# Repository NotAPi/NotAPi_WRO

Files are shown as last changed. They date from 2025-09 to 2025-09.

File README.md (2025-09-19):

# NotAPi_WRO_2025

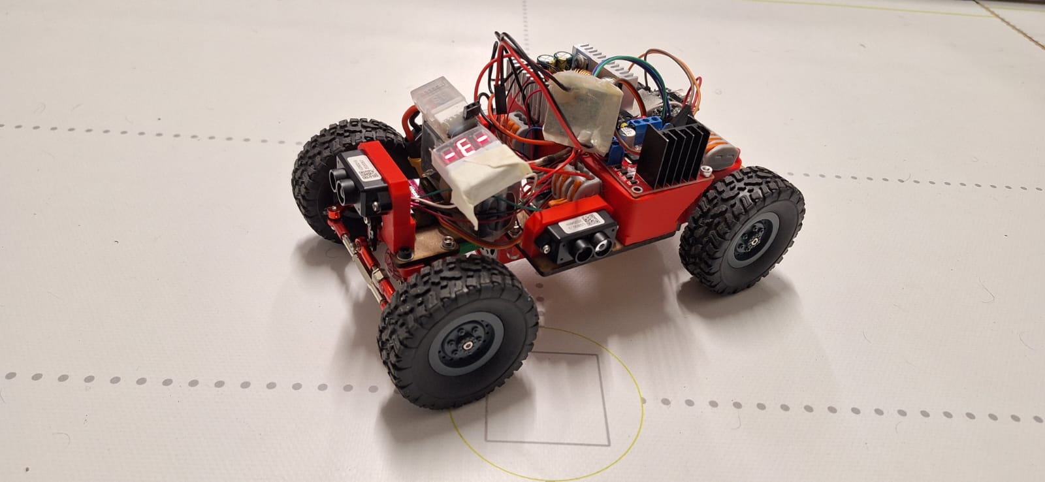
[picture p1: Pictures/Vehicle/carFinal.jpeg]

<!-- ![teamPhoto](https://raw.githubusercontent.com/NotAPi/NotAPi_WRO/refs/heads/2025/Pictures/Team/Imagen%20de%20WhatsApp%202024-05-25%20a%20las%2009.47.15_d164381c.jpg) -->

## 1. Mobility Management

For this version of the car we opted for a fresh start, we bought an [axle set](https://es.aliexpress.com/item/1005004716882834.html?gatewayAdapt=glo2esp) for managing directions and a pair of wheels to compliment it. Steering is controlled by a servo connected to the front axle, allowing it to turn in a fast manner.
For propulsion, we're using a recycled motor extracted from a dead vacuum cleaner, which we have tracked as being a [Transmotec GR-18260-CVC](https://www.transmotec.de/product/GR-18260-CVC/). For the previous car we made a pair of custom gears to reduce the speed and augment the torque, unfortunately, due to space constraints, we weren't able to use them (even though they aren't really necessary as the motor has enough torque to move the vehicle). The motor is managed by an L298N module, this provides us easy motor control. All additional structural components were 3D-printed or [lasercut](https://github.com/Pegoku/Diode-Laser-Cutter) for lightweight, durability and modularity and all models are available [here](https://github.com/NotAPi/NotAPi_WRO/tree/2025/Models).

**Key Features:**

- Servo-driven steering with 60º range
- New axle made specially for rc cars giving us a huge advantage in control, reliability and speed.
- A new motor with great power and rated for 12V, giving us a lot of torque and speed.
- Lightweight design with 3D-printed and lasercut components for durability and modularity.

---

## 2. Power and Sensor Management

### Power System

The robot is powered by a [650mAh 4S Li-Po battery](https://www.ihobbies.es/p?idsite=1&idioma=50&pdt_id=20281&error=solicitar_info&desc=).
To eficiently distribute the power, we used two step-down regulators:

- An adjustable Buck regulator (set to 12V) for the motor to allow it to yield optimal thrust in short periods of time, without the risk of overvolting it.
- A 5V LDO for all other components, as they don't draw much current.

### Sensors

The car currently employs a system of the following sensors:

- 3x LIDARs: LIDAR is a Time of Flight laser technology that allows for great precision and prevents interference from natural and ambience light, which was a weak spot for our previous sensors.
  They are located as follows:
- Front: Used to measure the distance of the walls and prevent the car from crashing into them.
- Both Sides: Used to measure distance of the walls, and used to know when and where to turn.
  They were set to I2C mode, and each one was assigned a different address using the [TF-Mini Plus library](https://github.com/budryerson/TFMini-Plus-I2C).
- Camera: Not used anymore.

### Schematic

A schematic of the electrical connections can be found [here](resources/schematic.pdf)

### BOM

| Items | Quantity | Links | Brief Description |
| --- | --- | --- | --- |
| TF-Mini | x3 | https://es.aliexpress.com/item/1005009430996831.html | Great Lidars now with the addition of (library for the tof) |
| Buck Regulator | x1 | https://es.aliexpress.com/item/1005004880411857.html | For the motor |
| L298N module | x1 | https://es.aliexpress.com/item/1005007650595037.html | Dual H-Bridge motor driver with integrated 5V regulator |
| DC motor (similar) | x1 | https://www.transmotec.de/product/GR-18260-CVC/ | Recycled from a vacuum cleaner, rated for 12V and with great torque |
| front and back Axles | x2 | https://es.aliexpress.com/item/1005004716882834.html?gatewayAdapt=glo2esp | Axle set that allows for the vehicle to maintain stability |
| Wheels | x4 | https://es.aliexpress.com/item/1005006889490468.html | Good wheels that although they often slip out. They pair well with the axle |
| ESP-32 | x1 | https://es.aliexpress.com/item/1005006456519790.html | Main controller, chosen for its power and ease of use |
| Servo | x1 | https://es.aliexpress.com/item/4000903254039.html | Used for steering |
| Battery | x1 | https://www.ihobbies.es/p?idsite=1&idioma=50&pdt_id=20281 | Provides power to the entire system |
| Motor | x1 | https://www.transmotec.es/product/GR-18260-CVC/ | Drives the vehicle forward |

---

## 3. Obstacle Management & Navigation Logic

### Navigation Logic

The car autonomously navigates by:

- Moving forward until the front LIDAR (TF-Mini) reports an obstacle closer than 90 cm.
- When the front distance drops below 90 cm it checks for an imminent crash (< 30 cm); if so, it reverses at full speed until the distance is greater than 40 cm, then, continues.
- Otherwise, it looks at both side sensors, goes back for roughly 1s to make room, and then steers towards the side with the greater distance while going forward for 2.5s while watching the front to avoid collisions.
- After the turn, it recenters the steering and returns to the forward loop.

### Flow Chart

This can be summarized in the following flow chart:

```mermaid
flowchart TD
  Start([Start]) --> Forward[Drive forward]
  Forward --> Fdist{Front distance < 90 cm?}
  Fdist -- No --> Forward
  Fdist -- Yes --> CrashCheck{Front < 30 cm?}
  CrashCheck -- Yes --> CrashRecover[Reverse until front > 40 cm]
  CrashRecover --> Forward
  CrashCheck -- No --> SideCheck{Left distance > Right distance?}
  SideCheck -- Yes --> TurnLeft[Reverse 1 s, steer left]
  SideCheck -- No --> TurnRight[Reverse 1 s, steer right]
  TurnLeft --> TurnExec[Drive turn for 2.5 s
   while monitoring front distance]
  TurnRight --> TurnExec
  TurnExec --> Forward
```

### Code Implementation

All this logic is implemented in the `main.cpp` file, which can be found [here](Code/ESP32/src/main.cpp).
For this project, we used the Arduino framework via PlatformIO, which simplified the development process significantly and allowed us to use existing Arduino libraries.

### Status LED Reference

The code also includes a list of status codes represented by the onboard LED:

- Startup: 5× rapid flashes (one-shot) - firmware just booted.
- SensorsInit: 3× medium flashes (one-shot) - sensor bus is being initialised.
- Idle / Ready: 1× short flash every ~0.8 s (repeating) - safe to press Start.
- DrivingForward: 2× short flashes (one-shot) - drivetrain commanded forward.
- TurningLeft: 3× short flashes with tight spacing (one-shot) - left turn routine.
- TurningRight: 3× short flashes with wider spacing (one-shot) - right turn routine.
- CrashRecovery: 5× very quick flashes (one-shot) - collision escape in progress.
- ForwardStuck: 4× short flashes (one-shot) - forward motion failed, backing up.
- ManualPause: 2× medium flashes with pause (repeating) - RC/manual mode active.
- Error: 1× long flash, long pause (repeating) - unrecoverable error, needs attention.

##### Uploaded to the ESP32

To upload the code to the ESP32, you need to have [PlatformIO CLI](https://platformio.org/) installed.

1. Connect the ESP32 board to your computer via USB.
2. Open a terminal and navigate to the `Code/ESP32` directory.
3. Run the following command to upload the code:
    ```bash
    pio run --target upload
    ```
4. Monitor the serial output (optional) by running:
    ```bash
    pio device monitor
    ```

### External Libraries Used

- [TF-Mini Plus I2C](https://registry.platformio.org/libraries/budryerson/TFMPI2C)
- [ESP32Servo](https://registry.platformio.org/libraries/madhephaestus/ESP32Servo)

---

## 4. Pictures

### Team Picture

Team Picture

### Car Pictures

<details>
  <summary>Car pictures (click to expand)</summary>
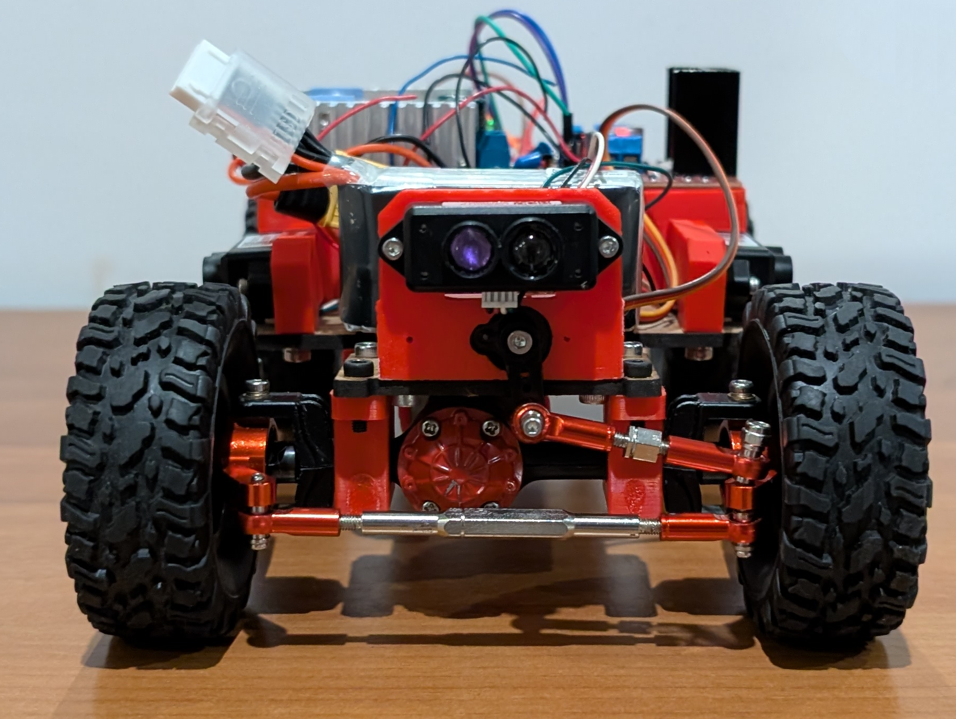
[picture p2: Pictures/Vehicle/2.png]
Car Picture 1
  
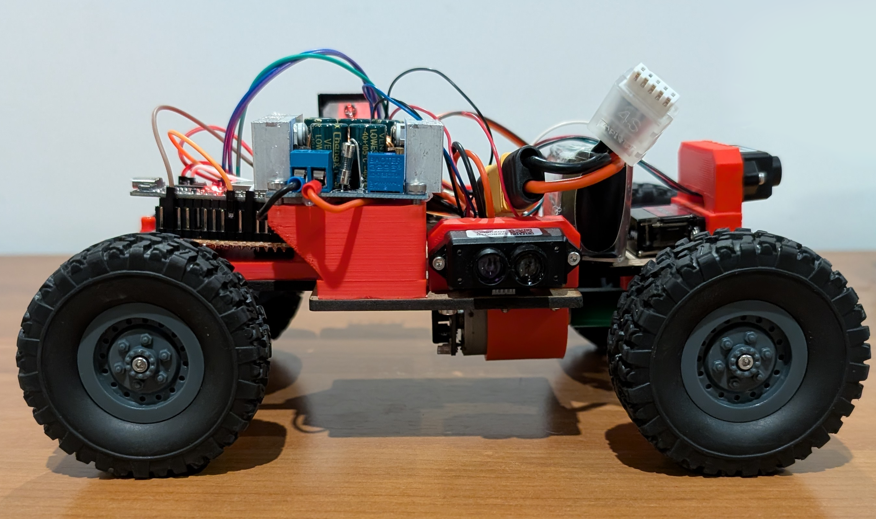
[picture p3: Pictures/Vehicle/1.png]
Car Picture 2
  
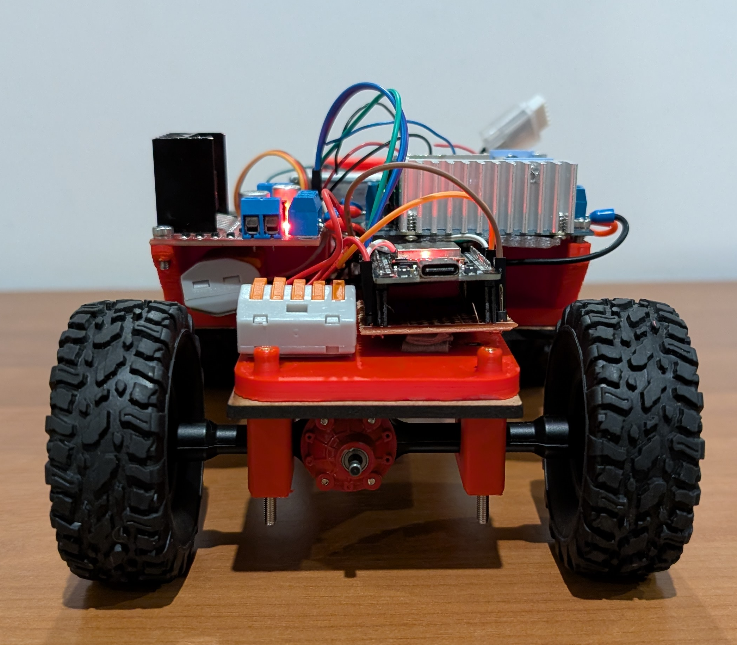
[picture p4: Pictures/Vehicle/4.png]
Car Picture 3
  
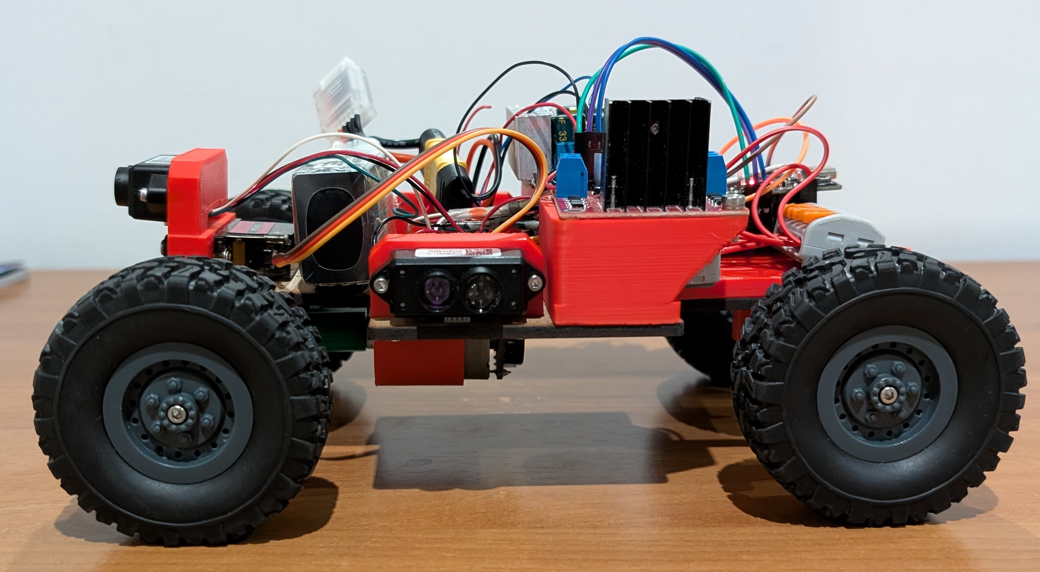
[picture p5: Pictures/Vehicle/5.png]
Car Picture 4
  
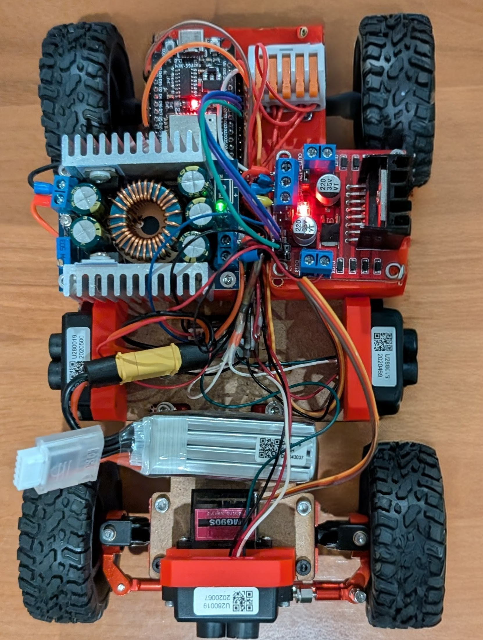
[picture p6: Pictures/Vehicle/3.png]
Car Picture 5
  
</details>

## 5. Performance Videos

[Demo](https://hc-cdn.hel1.your-objectstorage.com/s/v3/c7cb69626a8cc83b544aa8f92fb21f2a090f1fee_pxl_20250423_193522126_2.mp4)

[Demo2](https://hc-cdn.hel1.your-objectstorage.com/s/v3/c7cb69626a8cc83b544aa8f92fb21f2a090f1fee_pxl_20250423_193522126_2.mp4)

[Demo3](https://hc-cdn.hel1.your-objectstorage.com/s/v3/c7cb69626a8cc83b544aa8f92fb21f2a090f1fee_pxl_20250423_193522126_2.mp4)

---
_AI assistance:_ ChatGPT-5 (OpenAI) helped with part of the code, mainly the LightStatus functions and the `getSpeed()` function.

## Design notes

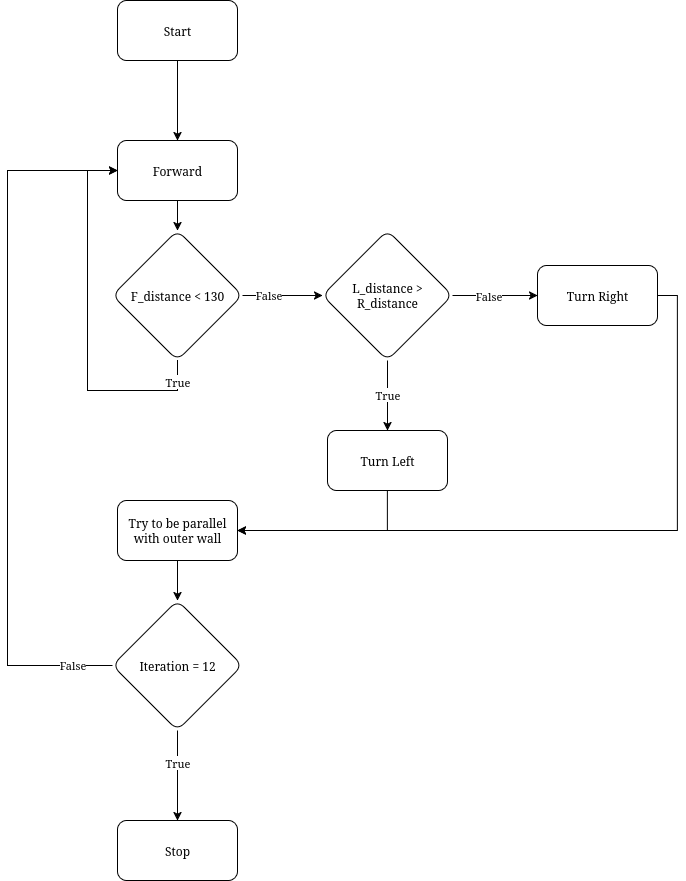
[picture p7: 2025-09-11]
resources/Diagram.png

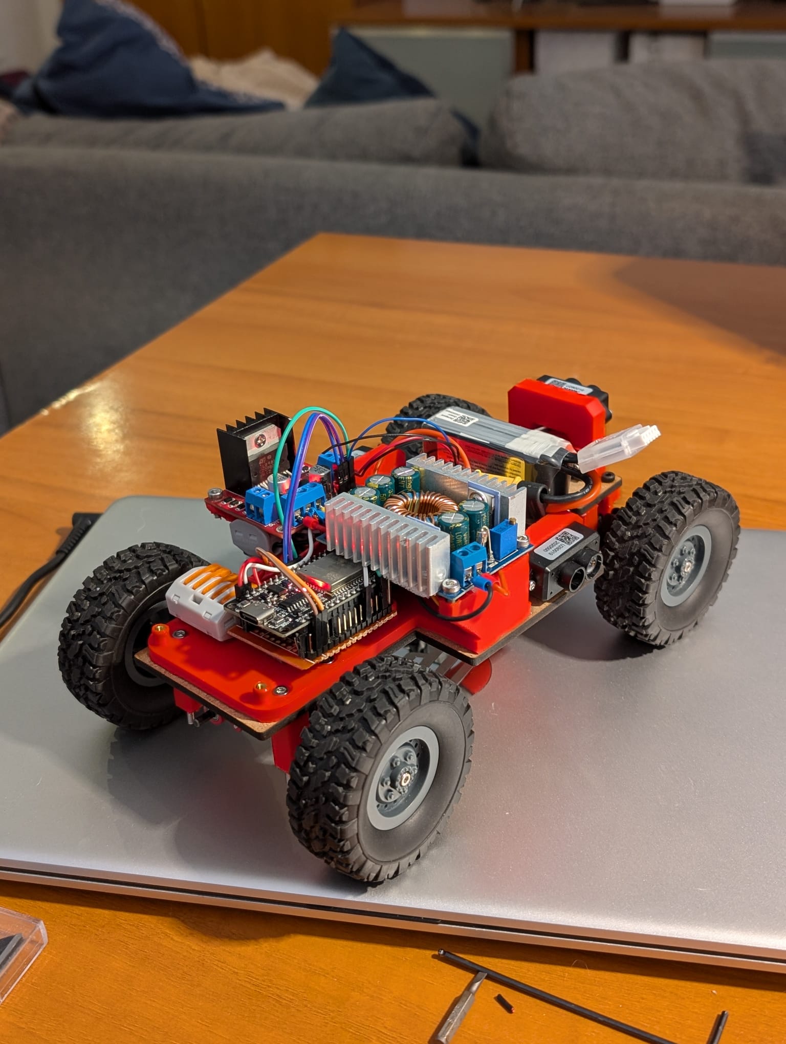
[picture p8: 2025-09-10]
resources/newimage.jpg

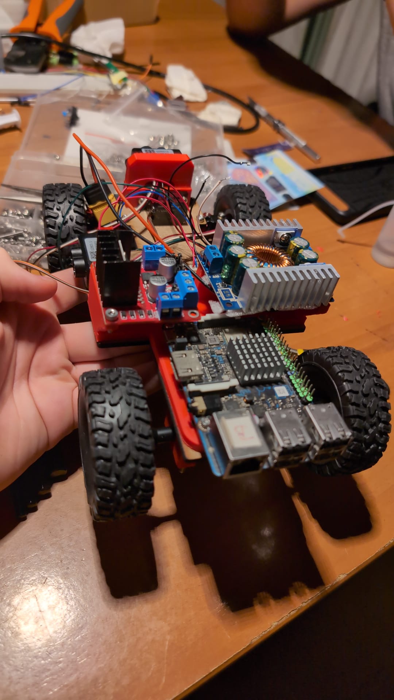
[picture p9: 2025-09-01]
resources/hetimage.jpg

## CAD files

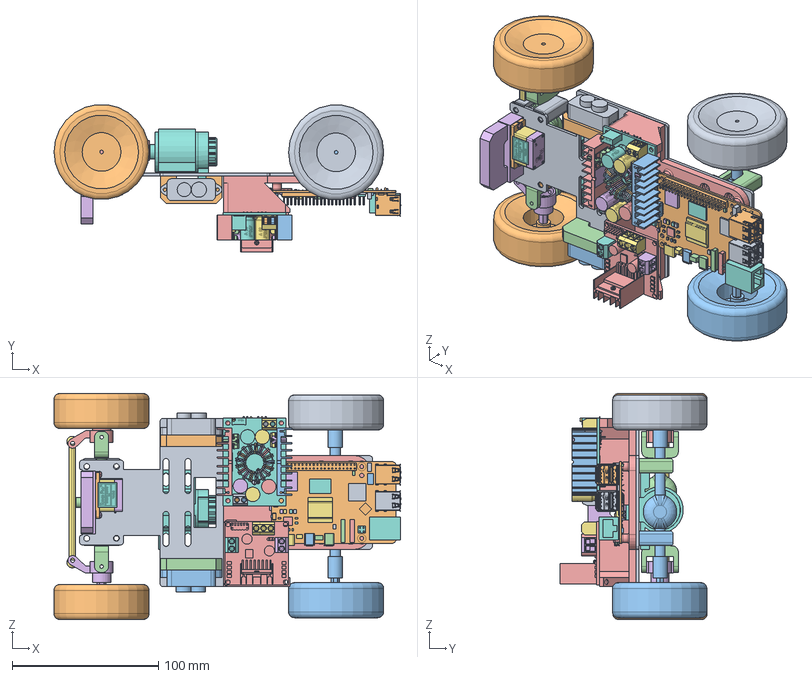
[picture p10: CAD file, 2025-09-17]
Models/couplings.FCStd
237.1 x 100.8 x 154.5 mm
Wheel1
RearAxis
FrontAxis
SpinnyThing1
SpinnyThing2
DirectionAxis
Motor
AxisScrewAdapter1
AxisScrewAdapter2
AxisScrewAdapter4
AxisScrewAdapter3
ShaftCoupler
ServoHolder
SG90 - Micro Servo 9g - Tower Pro.1_PeÂa
SG90 - Micro Servo 9g - Tower Pro.1_PeÂa001
SG90 - Micro Servo 9g - Tower Pro.1_PeÂa002
SG90 - Micro Servo 9g - Tower Pro.1_PeÂa003
SG90 - Micro Servo 9g - Tower Pro.1_PeÂa004
SG90 - Micro Servo 9g - Tower Pro.1_PeÂa005
SG90 - Micro Servo 9g - Tower Pro.1_PeÂa006
SG90 - Micro Servo 9g - Tower Pro.1_PeÂa007
SG90 - Micro Servo 9g - Tower Pro.1_PeÂa008
SG90 - Micro Servo 9g - Tower Pro.1_PeÂa009
SG90 - Micro Servo 9g - Tower Pro.1_PeÂa010
SG90 - Micro Servo 9g - Tower Pro.1_PeÂa011
SG90 - Micro Servo 9g - Tower Pro.1_PeÂa012
SG90 - Micro Servo 9g - Tower Pro.2_PeÂa
SG90 - Micro Servo 9g - Tower Pro.5_BS EN ISO 7045 - M2 x 8 - Z - 8S
SG90 - Micro Servo 9g - Tower Pro.5_BS EN ISO 7045 - M2 x 8 - Z - 8S001
SG90 - Micro Servo 9g - Tower Pro.6_BS EN ISO 7045 - M2 x 4 - Z - 4S
MotorSupport
Lidar
LidarSupport1
Lidar2
LidarSupport2
PiSupport
PCB_for REF 060923
PCB_for REF 060924
PCB_for REF 060925
PCB_for REF 060926
PCB_for REF 060927
PCB_for REF 060928
PCB_for REF 060929
PCB_for REF 060930
PCB_for REF 060931
PCB_for REF 060932
PCB_for REF 060933
PCB_for REF 060934
PCB_for REF 060935
PCB_for REF 060936
PCB_for REF 060937
PCB_for REF 060938
PCB_for REF 060939
PCB_for REF 060940
PCB_for REF 060941
PCB_for REF 060942
PCB_for REF 060943
PCB_for REF 060944
PCB_for REF 060945
PCB_for REF 060946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

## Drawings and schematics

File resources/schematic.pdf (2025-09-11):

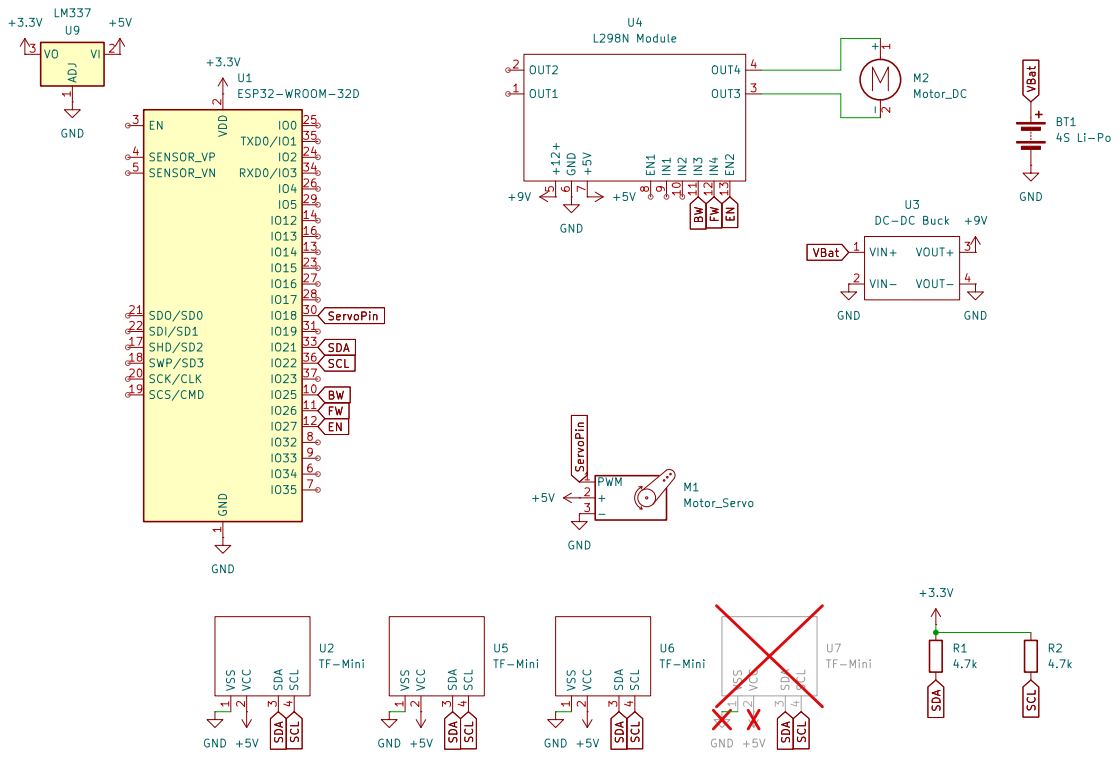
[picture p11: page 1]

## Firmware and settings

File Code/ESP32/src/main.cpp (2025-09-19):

#include <Arduino.h>
#include <Wire.h>
#include <ESP32Servo.h>
#include <TFMPI2C.h>

#include "lightCodes.h"

#define EN 25
#define FW 27
#define BW 26
#define ServoPin 18
#define StartButtonPin 0

#define TF_F 0x14
#define TF_L 0x13
#define TF_R 0x11

TFMPI2C tfm;

uint8_t SENSOR_ADDRS[] = {TF_F, TF_L, TF_R};
const size_t NUM_SENSORS = sizeof(SENSOR_ADDRS) / sizeof(SENSOR_ADDRS[0]);

const int SDA_PIN = 21;
const int SCL_PIN = 22;

const unsigned long TF_READ_PERIOD_MS = 20; // 50 Hz do not go above 100Hz
unsigned long lastTFReadMs = 0;

const unsigned long TF_PRINT_PERIOD_MS = 100; // print every 100 ms
unsigned long lastTFPrintMs = 0;

const char *SENSOR_NAMES[] = {"Front", "Left", "Right"};

Servo driveServo;
int servoAngle = 90;
int speed = 230; // 0-255
bool canStart = false;
int stuckCounter = 0;
const int unstuckSpeed = 255;

const int F_dis_TH = 90;         // cm
const int F_dis_Crash_TH = 30;    // cm
const int F_dis_uncrash_TH = 40; // cm
const int Min_Distance_turn = 70; // cm
const int WALL_DIS_TH = 60;       // cm
const int TURN_TIME_MS = 2500;    // ms; minimum time to turn
const int forwardSince = 0;
const int Max_Speed = 200; // cm/s // ik it low but

const int MOTOR_PWM_CH = 8;
const int MOTOR_PWM_FREQ = 5000;
const int MOTOR_PWM_RES = 8; // 8-bit resolution4.34+5.5 mm

int TF_F_DISTANCE;
int TF_L_DISTANCE;
int TF_R_DISTANCE;

const size_t FRONT_DISTANCE_HISTORY = 10;
int frontDistanceHistory[FRONT_DISTANCE_HISTORY] = {-1, -1, -1, -1, -1, -1, -1, -1, -1, -1};
size_t frontDistanceHistoryIndex = 0;
size_t frontDistanceHistoryCount = 0;
unsigned long frontDistanceTimeHistory[FRONT_DISTANCE_HISTORY] = {0};

void clearFrontDistanceHistory()
{
    frontDistanceHistoryIndex = 0;
    frontDistanceHistoryCount = 0;
    for (size_t i = 0; i < FRONT_DISTANCE_HISTORY; ++i)
    {
        frontDistanceHistory[i] = -1;
        frontDistanceTimeHistory[i] = 0;
    }
}

int getDistance(uint8_t addr)
{
    int16_t dist = 0, flux = 0, temp = 0;

    tfm.getData(dist, flux, temp, addr);
    return dist;
}

float getSpeed()
{
    if (frontDistanceHistoryCount < 2)
    {
        return 0.0f;
    }

    size_t newestIndex = (frontDistanceHistoryIndex + FRONT_DISTANCE_HISTORY - 1) % FRONT_DISTANCE_HISTORY;
    size_t oldestIndex = (frontDistanceHistoryCount == FRONT_DISTANCE_HISTORY) ? frontDistanceHistoryIndex : 0;

    unsigned long newestTime = frontDistanceTimeHistory[newestIndex];
    unsigned long oldestTime = frontDistanceTimeHistory[oldestIndex];

    if (newestTime <= oldestTime)
    {
        return 0.0f;
    }

    int newestDistance = frontDistanceHistory[newestIndex];
    int oldestDistance = frontDistanceHistory[oldestIndex];

    float distanceDelta = static_cast<float>(oldestDistance - newestDistance);
    float timeDeltaSeconds = (newestTime - oldestTime) / 1000.0f;

    return distanceDelta / timeDeltaSeconds;
}

bool isForwardStuck()
{
    if (frontDistanceHistoryCount < 4)
    {
        return false;
    }

    int minDistance = frontDistanceHistory[0];
    int maxDistance = frontDistanceHistory[0];
    for (size_t i = 1; i < frontDistanceHistoryCount; ++i)
    {
        if (frontDistanceHistory[i] < minDistance)
        {
            minDistance = frontDistanceHistory[i];
        }
        if (frontDistanceHistory[i] > maxDistance)
        {
            maxDistance = frontDistanceHistory[i];
        }
    }

    bool nearZero = maxDistance <= 5;
    bool lowVariance = (maxDistance - minDistance) <= 3;

    return nearZero && lowVariance;
}



void setSpeed(int spd)
{
    // Serial.print("Setting speed to ");
    // Serial.println(spd);
    if (spd < 0)
        spd = 0;
    if (spd > 255)
        spd = 255;

    if (getDistance(TF_F) > Min_Distance_turn)
    {
        bool forwardActive = digitalRead(FW) == HIGH && digitalRead(BW) == LOW;
        if (forwardActive && spd > 0)
        {
            float currentSpeed = getSpeed();
            if (currentSpeed > Max_Speed)
            {
                spd = 0;
                Serial.println("Speed limit exceeded");
            }
        }
    }
    // Serial.print("Set speed to ");
    // Serial.println(spd);
    ledcWrite(EN, spd);
}

void forward()
{
    Serial.println("FORWARD");
    setSpeed(speed);
    digitalWrite(FW, HIGH);
    digitalWrite(BW, LOW);
}

void backward()
{
    digitalWrite(FW, LOW);
    digitalWrite(BW, HIGH);
}

void stop()
{
    digitalWrite(FW, LOW);
    digitalWrite(BW, LOW);
}

void turn(int angle) // for int
{
    Serial.println(angle);
    if (angle < 60)
        angle = 60;
    if (angle > 120)
        angle = 120;
    driveServo.write(angle);
}

void turn(char dir) // for char
{
    if (dir == 'L')
        turn(120);
    else if (dir == 'R')
        turn(60);
    else
        turn(90);
}

bool checkIfStuck()
{
    if (frontDistanceHistoryCount < 2)
    {
        return false;
    }

    size_t newestIndex = (frontDistanceHistoryIndex + FRONT_DISTANCE_HISTORY - 1) % FRONT_DISTANCE_HISTORY;
    size_t oldestIndex = (frontDistanceHistoryCount == FRONT_DISTANCE_HISTORY) ? frontDistanceHistoryIndex : 0;

    int newestDistance = frontDistanceHistory[newestIndex];
    int oldestDistance = frontDistanceHistory[oldestIndex];

    if ((newestDistance + oldestDistance) / 2 < 12)
    {
        return true;
    }
    return false;
}

void attemptForwardUnstuck()
{
    Serial.println("FORWARD STUCK - REVERSING");
    setStatus(StatusCode::ForwardStuck);
    backward();
    setSpeed(unstuckSpeed);
    delayWithStatusLEDUpdate(500);
    stop();
    setSpeed(0);
    delayWithStatusLEDUpdate(200);
    clearFrontDistanceHistory();
}

void setup()
{
    ESP32PWM::allocateTimer(1); // PWM timer 1
    ESP32PWM::allocateTimer(2); // PWM timer 2
    ESP32PWM::allocateTimer(3); // PWM timer 3
    Serial.begin(115200);
    Serial.println("Hello World!");
    initStatusLED();
    setStatus(StatusCode::Startup);
    printStatusList(Serial);
    delayWithStatusLEDUpdate(1000);
    // driveServo.attach(ServoPin);
    if (driveServo.attach(ServoPin) < 0) // some servo fix ?
    {
        driveServo.detach();
        ledcDetach(ServoPin);
        delayWithStatusLEDUpdate(100);
        driveServo.attach(ServoPin);
    }
    delayWithStatusLEDUpdate(2000);
    driveServo.write(90); // Center the servo
    // Initialize I2C bus and recover if needed
    tfm.recoverI2CBus(SDA_PIN, SCL_PIN);
    Wire.setClock(400000); // 400kHz I2C
    delayWithStatusLEDUpdate(100);
    setStatus(StatusCode::SensorsInit);

    // Send example commands to all TFMini-Plus sensors
    for (size_t i = 0; i < NUM_SENSORS; ++i)
    {
        uint8_t addr = SENSOR_ADDRS[i];

        Serial.print("Sensor @0x");
        if (addr < 16)
            Serial.print('0');
        Serial.print(addr, HEX);
        Serial.print(" - System reset: ");

        if (tfm.sendCommand(SOFT_RESET, 0, addr))
        {
            Serial.println("passed.");
        }
        else
        {
            tfm.printReply();
        }

        delayWithStatusLEDUpdate(50);

        Serial.print("Sensor @0x");
        if (addr < 16)
            Serial.print('0');
        Serial.print(addr, HEX);
        Serial.print(" - Firmware version: ");

        if (tfm.sendCommand(GET_FIRMWARE_VERSION, 0, addr))
        {
            Serial.print(tfm.version[0]);
            Serial.print('.');
            Serial.print(tfm.version[1]);
            Serial.print('.');
            Serial.println(tfm.version[2]);
        }
        else
        {
            tfm.printReply();
        }
    }
    delayWithStatusLEDUpdate(10);
    setStatus(StatusCode::Idle);

    pinMode(EN, OUTPUT);                                      // EN Pin
    ledcAttachChannel(EN, MOTOR_PWM_FREQ, MOTOR_PWM_RES, 10); // EN Pin
    pinMode(FW, OUTPUT);                                      // FW Pin
    pinMode(BW, OUTPUT);                                      // BW Pin
    pinMode(StartButtonPin, INPUT_PULLDOWN);

    digitalWrite(EN, LOW);
    digitalWrite(FW, LOW);
    digitalWrite(BW, LOW);
}

void loop()
{
    updateStatusLED();

    // Non-blocking periodic read/print of all TF-Mini sensors every second
    if (digitalRead(StartButtonPin) == LOW && !canStart)
    {
        canStart = true;
        setSpeed(speed);
        delayWithStatusLEDUpdate(2000);
        turn(90);
        setStatus(StatusCode::DrivingForward);
    }
    else if (digitalRead(StartButtonPin) == LOW && canStart)
    {
        canStart = false;
        stop();
        setSpeed(0);
        delayWithStatusLEDUpdate(2000);
        turn(90);
        setStatus(StatusCode::ManualPause);
    }

    // CAR LOGIC ALGORITHM:
    // START:
    // F_dis > F_dis_TH -> forward
    // F_dis < F_dis_TH -> stop -> L_dis > R_dis ? turn left : turn right
    // DO PID to try to keep OUTER WALL distance = WALL_DIS_TH (not implemented)
    // LOOP
    if (!canStart)
    {
        if (getStatus() != StatusCode::Idle)
        {
            setStatus(StatusCode::Idle);
        }
        delayWithStatusLEDUpdate(100);
        // return;
    }
    else
    {
        unsigned long now = millis();

        if (now - lastTFReadMs >= TF_READ_PERIOD_MS)
        {
            lastTFReadMs = now;
            size_t historyCountBeforeUpdate = frontDistanceHistoryCount;
            int prevFrontMaxDistance = -1;
            if (frontDistanceHistoryCount > 0)
            {
                prevFrontMaxDistance = frontDistanceHistory[0];
                for (size_t i = 1; i < frontDistanceHistoryCount; ++i)
                {
                    if (frontDistanceHistory[i] > prevFrontMaxDistance)
                    {
                        prevFrontMaxDistance = frontDistanceHistory[i];
                    }
                }
            }
            TF_F_DISTANCE = getDistance(TF_F);
            TF_L_DISTANCE = getDistance(TF_L);
            TF_R_DISTANCE = getDistance(TF_R);

            frontDistanceHistory[frontDistanceHistoryIndex] = TF_F_DISTANCE;
            frontDistanceTimeHistory[frontDistanceHistoryIndex] = now;
            frontDistanceHistoryIndex = (frontDistanceHistoryIndex + 1) % FRONT_DISTANCE_HISTORY;
            if (frontDistanceHistoryCount < FRONT_DISTANCE_HISTORY)
            {
                frontDistanceHistoryCount++;
            }

            Serial.print("F: ");
            Serial.print(TF_F_DISTANCE);
            Serial.print(" L: ");
            Serial.print(TF_L_DISTANCE);
            Serial.print(" R: ");
            Serial.print(TF_R_DISTANCE);
            Serial.print(" Speed: ");
            Serial.print(getSpeed());
            Serial.println(" cm/s");

            if (checkIfStuck())
            {
                Serial.println("POSSIBLY STUCK");

                while (true)
                {
                    Serial.print("Speed history: ");
                    for (size_t i = 0; i < frontDistanceHistoryCount; ++i)
                    {
                        Serial.print(frontDistanceHistory[i]);
                        Serial.print(" ");
                    }
                    Serial.println();
                    delayWithStatusLEDUpdate(1000);
                }
            }

            if (TF_F_DISTANCE < F_dis_Crash_TH )//&& servoAngle == 90 || TF_F_DISTANCE < F_dis_Crash_TH - 20 && servoAngle != 90) // CRASH DETECTED
            {
                int stuck = 0;
                Serial.println("CRASH! STOP");
                setStatus(StatusCode::CrashRecovery);
                backward();
                setSpeed(200);
                delayWithStatusLEDUpdate(100);
                int startTime = millis();
                while (getDistance(TF_F) < F_dis_uncrash_TH)
                {
                    int prevDistance = getDistance(TF_F);
                    delayWithStatusLEDUpdate(50);
                    // if (getSpeed() < 10) // if not getting away, break
                    // {
                    //     setSpeed(255);
                    // }

                    if (millis() - startTime > 8000)
                    {
                        // canStart = false; // if stuck for 8s, stop
                        Serial.println("UNABLE TO UNSTUCK, WAIT FOR MANUAL RESET");
                    }
                    else if (millis() - startTime > 2000)
                    {
                        // setSpeed(255); // after 2s, go full speed
                        backward();
                        delayWithStatusLEDUpdate(700);
                        forward();
                        delayWithStatusLEDUpdate(500);
                        backward();
                        delayWithStatusLEDUpdate(700);

                        stuck++;
                    }
                    if (stuck != 0)
                    {
                        backward();
                        delayWithStatusLEDUpdate(500);
                    }
                }

                if (stuck == 1)
                {
                }
                stop();
                setSpeed(0);
                turn(90);
                // canStart = false;
                delayWithStatusLEDUpdate(500);
                return; // wait for manual restart
            }
            // else if (historyCountBeforeUpdate == FRONT_DISTANCE_HISTORY &&
            //          prevFrontMaxDistance - TF_F_DISTANCE > 1 /*&& forwardSince > 3000*/) // possibly stuck detect
            // {
            //     Serial.println("POSSIBLY STUCK");
            //     stuckCounter++;
            //     if (stuckCounter > 3)
            //     {
            //         Serial.println("STUCK! ");
            //         stuckCounter = 3; // max 3
            //         while (prevFrontMaxDistance - TF_F_DISTANCE > 2)
            //         {
            //             Serial.println("STUCK! UNSTUCKING");
            //             TF_F_DISTANCE = getDistance(TF_F);
            //             delay(50);
            //             setSpeed(unstuckSpeed);
            //             backward();
            //             delay(500);
            //             forward();
            //             delay(500);
            //             backward();
            //             delay(1000);
            //             setSpeed(speed);
            //         }
            //         stuckCounter = 0;
            //     }
            // return;
            // }

            if (TF_F_DISTANCE > F_dis_TH)
            {

                forward();
                setSpeed(speed);
                setStatus(StatusCode::DrivingForward, false);
                if (isForwardStuck())
                {
                    attemptForwardUnstuck();
                    return;
                }
                // if (TF_L_DISTANCE < WALL_DIS_TH)
                // {
                //     turn(120); // turn right
                // }
                // else if (TF_R_DISTANCE < WALL_DIS_TH)
                // {
                //     turn(60); // turn left
                // }
                // else
                // {
                turn(90); // go straight
                // }
            }
            else // too close to front wall, turn
            {
                char turnDirection;
                // stop();
                backward();
                setSpeed(200);
                delayWithStatusLEDUpdate(1000);
                while (getDistance(TF_F) < Min_Distance_turn)
                {
                    int prevDistance = getDistance(TF_F);
                    delayWithStatusLEDUpdate(50);
                    if (prevDistance - getDistance(TF_F) < 5) // if not getting away, break
                        break;
                }

                // delay(100);
                int prevTurnDistance = getDistance(TF_F);
                if (TF_L_DISTANCE > TF_R_DISTANCE) //&& TF_L_DISTANCE > WALL_DIS_TH)
                {
                    setStatus(StatusCode::TurningLeft);
                    turn('L'); // turn left
                    Serial.println("TURN LEFT");
                    turnDirection = 'L';
                }
                else
                {
                    setStatus(StatusCode::TurningRight);
                    turn('R'); // turn right
                    Serial.println("TURN RIGHT");
                    turnDirection = 'R';
                }
                // delay(100);
                forward();
                setSpeed(speed);
                int turnStartTime = millis();
                while ((millis() - turnStartTime) < TURN_TIME_MS)
                // delay(TURN_TIME_MS);
                {
                    delayWithStatusLEDUpdate(50);
                    // check if crash
                    if (getDistance(TF_F) < F_dis_Crash_TH)
                    {
                        turn(90);
                        return;
                    } 
                }
                setStatus(StatusCode::DrivingForward);

                if (getSpeed() == 0) // STUCK
                {
                    Serial.println("STUCK IN TURN, TRY AGAIN");
                    backward();
                    while (getSpeed() < 5)
                    {
                        backward();
                        delayWithStatusLEDUpdate(500);
                        forward();
                        delayWithStatusLEDUpdate(500);
                    }
                }

                // // turn until L and R are similar distance (10% tolerance) or timeout 2s
                // unsigned long startTime = millis();
                // while (millis() - startTime < 2000)
                // {
                //     TF_L_DISTANCE = getDistance(TF_L);
                //     TF_R_DISTANCE = getDistance(TF_R);
                //     if (abs(TF_L_DISTANCE - TF_R_DISTANCE) < 0.2 * TF_R_DISTANCE)
                //     {
                //         break;
                //     }
                // }

                // continue turning until the outer sensor distance starts to increase
                int outerSensor = (turnDirection == 'L') ? TF_R : TF_L;
                int previousOuterDistance = getDistance(outerSensor);
                while (true)
                {
                    int currentOuterDistance = getDistance(outerSensor);
                    if (currentOuterDistance > previousOuterDistance)
                    {
                        break;
                    }
                    previousOuterDistance = currentOuterDistance;
                }

                // try to correct the angle a bit
                setSpeed(180);
                // if (turnDirection == 'L')
                //     turn('R'); // turn left
                // else
                //     turn('L'); // turn right
                delayWithStatusLEDUpdate(20);
                turn(90); // go straight
            }

            // for ()
            // {
            //     uint8_t addr = SENSOR_ADDRS[i];
            //     int distance = getDistance(addr);

            //     Serial.print(SENSOR_NAMES[i]);
            //     Serial.print(" (0x");
            //     if (addr < 16)
            //         Serial.print('0');
            //     Serial.print(addr, HEX);
            //     Serial.print("): ");
            //     if (distance >= 0)
            //     {
            //         Serial.print(distance);
            //         Serial.println(" mm");
            //     }
            //     else
            //     {
            //         Serial.println("Error");
            //     }
            // }
            // Serial.println();
        }
    }
    // THIS IS FOR DEBUGGING VIA SERIAL MONITOR, (RC CAR MODE)
    char input;
    if (Serial.available() > 0)
    {
        int raw = Serial.read();
        if (raw >= 0)
        {
            input = (char)raw;
        }
        Serial.print("You entered: ");
        Serial.println(input);
        Serial.flush();

        switch (input)
        {
        case 'w':
            setSpeed(0);
            delayWithStatusLEDUpdate(100);
            forward();
            setSpeed(speed);
            setStatus(StatusCode::DrivingForward, false);
            break;

        case 's':
            setSpeed(0);
            delayWithStatusLEDUpdate(100);
            backward();
            setSpeed(speed);
            setStatus(StatusCode::ManualPause, false);
            break;

        case 'a':
            if (servoAngle < 120)
            {
                servoAngle += 10;
            }
            driveServo.write(servoAngle);
            Serial.println(servoAngle);
            break;

        case 'd':
            if (servoAngle > 60)
            {
                servoAngle -= 10;
            }
            driveServo.write(servoAngle);
            Serial.println(servoAngle);
            break;

        case 'e':
            if (speed >= 10025)
            {
                speed = 255;
            }
            else
            {
                speed += 25;
            }
            setSpeed(speed);
            Serial.println(speed);
            break;
        case 'q':
            if (speed <= 30)
            {
                speed = 0;
            }
            else
            {
                speed -= 25;
            }
            setSpeed(speed);
            Serial.println(speed);
            break;
        case 'p':
            if (!canStart)
            {
                canStart = true;
                setSpeed(speed);
                setStatus(StatusCode::DrivingForward);
                delayWithStatusLEDUpdate(2000);
                turn(90);
            }
            else if (canStart)
            {
                canStart = false;
                stop();
                setSpeed(0);
                setStatus(StatusCode::ManualPause);
                delayWithStatusLEDUpdate(2000);
                turn(90);
            }
        default:
            setSpeed(0);
            stop();
            setStatus(StatusCode::ManualPause, false);
            break;
        }
    }
    delayWithStatusLEDUpdate(5);
}

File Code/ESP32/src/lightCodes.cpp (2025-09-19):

#include "lightCodes.h"

namespace
{
    struct LedFlashState
    {
        bool active = false;
        bool repeat = false;
        uint8_t totalFlashes = 0;
        uint8_t flashesCompleted = 0;
        bool ledOn = false;
        unsigned long lastChangeMs = 0;
        uint16_t onDurationMs = 0;
        uint16_t offDurationMs = 0;
    };

    LedFlashState flashState;
    uint8_t ledPin = LED_BUILTIN;
    StatusCode currentStatus = StatusCode::Startup;

    const StatusPattern *findPattern(StatusCode code)
    {
        for (size_t i = 0; i < STATUS_PATTERNS_COUNT; ++i)
        {
            if (STATUS_PATTERNS[i].code == code)
            {
                return &STATUS_PATTERNS[i];
            }
        }
        return nullptr;
    }
}

// LIST OF THE STATUS PATTERNS
const StatusPattern STATUS_PATTERNS[] = {
    {StatusCode::Startup, "Startup", 5, 120, 120, false},
    {StatusCode::SensorsInit, "SensorsInit", 3, 200, 200, false},
    {StatusCode::Idle, "Idle", 1, 200, 600, true},
    {StatusCode::DrivingForward, "DrivingForward", 2, 90, 160, false},
    {StatusCode::TurningLeft, "TurningLeft", 3, 90, 90, false},
    {StatusCode::TurningRight, "TurningRight", 3, 90, 250, false},
    {StatusCode::CrashRecovery, "CrashRecovery", 5, 70, 70, false},
    {StatusCode::ForwardStuck, "ForwardStuck", 4, 100, 100, false},
    {StatusCode::ManualPause, "ManualPause", 2, 200, 600, true},
    {StatusCode::Error, "Error", 1, 1000, 1000, true},
};

const size_t STATUS_PATTERNS_COUNT = sizeof(STATUS_PATTERNS) / sizeof(STATUS_PATTERNS[0]);

void initStatusLED(uint8_t pin)
{
    ledPin = pin;
    pinMode(ledPin, OUTPUT);
    digitalWrite(ledPin, LOW);
    flashState = LedFlashState{};
}

void flashStatusLED(uint8_t flashes, uint16_t onMs, uint16_t offMs)
{
    if (flashes == 0)
    {
        return;
    }

    flashState.totalFlashes = flashes;
    flashState.onDurationMs = onMs;
    flashState.offDurationMs = offMs;
    flashState.flashesCompleted = 1;
    flashState.ledOn = true;
    flashState.active = true;
    flashState.repeat = false;
    flashState.lastChangeMs = millis();

    digitalWrite(ledPin, HIGH);
}

bool isStatusLEDFlashing()
{
    return flashState.active;
}

void triggerStatusPattern(StatusCode code)
{
    const StatusPattern *pattern = findPattern(code);
    if (pattern != nullptr && pattern->flashes > 0)
    {
        flashStatusLED(pattern->flashes, pattern->onMs, pattern->offMs);
        flashState.repeat = pattern->repeat;
    }
    else
    {
        flashState.active = false;
        flashState.repeat = false;
        digitalWrite(ledPin, LOW);
    }
}

void setStatus(StatusCode code, bool retriggerPattern)
{
    if (code == currentStatus && !retriggerPattern)
    {
        return;
    }

    currentStatus = code;

    if (retriggerPattern)
    {
        triggerStatusPattern(code);
    }
}

StatusCode getStatus()
{
    return currentStatus;
}

void updateStatusLED()
{
    if (!flashState.active)
    {
        return;
    }

    unsigned long now = millis();

    if (flashState.ledOn)
    {
        if (now - flashState.lastChangeMs >= flashState.onDurationMs)
        {
            digitalWrite(ledPin, LOW);
            flashState.ledOn = false;
            flashState.lastChangeMs = now;

            if (flashState.flashesCompleted >= flashState.totalFlashes)
            {
                if (flashState.repeat)
                {
                    flashState.flashesCompleted = 0;
                }
                else
                {
                    flashState.active = false;
                }
            }
        }
    }
    else
    {
        if (flashState.flashesCompleted >= flashState.totalFlashes && !flashState.repeat)
        {
            flashState.active = false;
            return;
        }

        if (now - flashState.lastChangeMs >= flashState.offDurationMs)
        {
            digitalWrite(ledPin, HIGH);
            flashState.ledOn = true;
            flashState.lastChangeMs = now;
            flashState.flashesCompleted++;
        }
    }
}

void delayWithStatusLEDUpdate(unsigned long durationMs)
{
    unsigned long start = millis();
    while (millis() - start < durationMs)
    {
        updateStatusLED();
        delay(1);
    }
}

void printStatusList(Stream &out)
{
    out.println(F("Status Codes:"));
    for (size_t i = 0; i < STATUS_PATTERNS_COUNT; ++i)
    {
        out.print(F("  ["));
        out.print(static_cast<int>(STATUS_PATTERNS[i].code));
        out.print(F("] "));
        out.print(STATUS_PATTERNS[i].name);
        out.print(F(" -> flashes:"));
        out.print(STATUS_PATTERNS[i].flashes);
        out.print(F(" on:"));
        out.print(STATUS_PATTERNS[i].onMs);
        out.print(F("ms off:"));
        out.print(STATUS_PATTERNS[i].offMs);
        out.print(F("ms repeat:"));
        out.println(STATUS_PATTERNS[i].repeat ? F("yes") : F("no"));
    }
}

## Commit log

2025-05-09 I am tired
2025-08-13 V1 base
    [couplings-AxisScrewAdapter.dxf, couplings-AxisScrewAdapter.step, couplings.FCStd]
2025-08-18 CAD basics
    [couplings-Body.stl, couplings.FCStd]
2025-08-18 adapt cad base + motor holder
    [couplings-Body.stl, couplings-Body015.stl, couplings.FCStd]
2025-08-25 add Lidar supports + other
    [couplings-LidarRLidarSupport1.step, couplings-LidarSupport1.stl, couplings-ServoHolder.step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]
2025-08-25 fix screwAdapter thing
    [base.step, couplings-AxisScrewAdapter.step, couplings.FCStd]
2025-08-27 better motor support, and pi support (WIP)
    [couplings.FCStd]
2025-08-27 finished support for the components
    [couplings-MotorSupport.step, couplings-PiSupport.step, couplings.FCStd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]
2025-09-03 Deleted previous year files
    [186502S.kicad_pcb, 186502S.kicad_sch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]
2025-09-09 halfcommit
    more tomorrow 👍
2025-09-10 add servo drive
2025-09-10 add Schematic
    [Schematic.kicad_sch]
2025-09-10 fix schematic
    [Schematic.kicad_sch]
2025-09-10 use a case/switch instead of IF
2025-09-10 fix servo direction
2025-09-10 Revise power and sensor management sections in README
    Something
2025-09-11 Revise README with updated car features and components
    Updated features and specifications for the car, including new components and modifications. Added a schematic and BOM for better understanding.
2025-09-11 Correct description casing for 12V Regulator
2025-09-11 Update README with schematic and BOM reference
2025-09-11 continue docs
    [Schematic.kicad_sch]
2025-09-12 fix flowchart
2025-09-15 clean Models folder
    [CamSupport.FCStd, L298Nsoporte.FCStd, MOTORsoporteFINAL3.step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]
2025-09-16 move schematic src files
    [Schematic.kicad_sch]
2025-09-17 reversed axis of the motor, so also reversed the direction. Fix
    [couplings.FCStd]
2025-09-17 use boot button to start car
2025-09-18 fixes + add 'P' (via serial) as toggle canStart
    [main.cpp]
2025-09-18 fix + add function to use char and also int
    [main.cpp]
2025-09-18 add backward movement when stuck detected in loop
    [main.cpp]
2025-09-18 add stuck detection and recovery logic in loop
    [main.cpp]
2025-09-19 add front distance history tracking and improve stuck detection logic
    [main.cpp]
2025-09-19 remove stuck code cause it's broken
    [main.cpp]
2025-09-19 add stuck action on turn
    [main.cpp]
2025-09-19 refine distance thresholds and enhance stuck detection logic
    [main.cpp]
2025-09-19 add status LED status patterns
